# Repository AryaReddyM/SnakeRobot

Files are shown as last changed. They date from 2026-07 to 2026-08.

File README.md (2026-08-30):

# Teleoperated Snake Robot

A six-segment serpentine robot built with the intention to aid in search and rescue efforts where people or other robots cannot help. It is fully untethered, controlled over Bluetooth from an Xbox controller, and has a forward-facing camera.

I chose this form factor because I thought snake robots would be better suited for confined-space inspection where wheeled or legged robots can't fit. This is a testbed for that mechanism, not a deployable system.

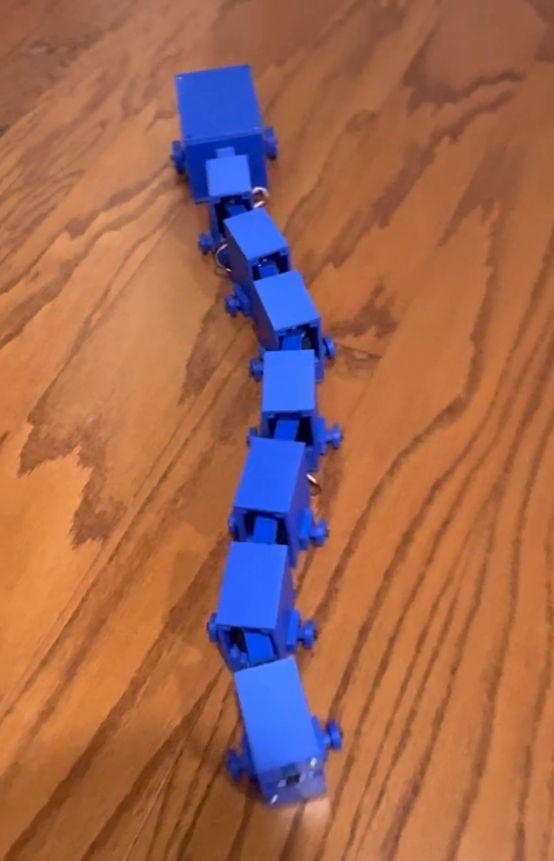
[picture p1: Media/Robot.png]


[Robot Demo](https://youtube.com/shorts/Uw1LnG1LLQQ?feature=share)

## What it does

- Travels forward on flat hard surfaces with a sinusoidal traveling-wave gait
- Steers through a graded joint offset that arcs the body, though turning is weak
- Streams video from an ESP32-CAM

## Hardware

- **Servos** - 6× Feetech STS3215 serial bus servos
- **Main controller** - ESP32-WROVER
- **Servo interface** - Waveshare serial bus servo driver board
- **Camera** - ESP32-CAM
- **Power** - 2S 7.4V LiPo, 1500mAh, with LM2596 buck converters to step down voltage for ESP32s
- **Control** - Xbox controller over Bluetooth via Bluepad32
- **Structure** - 3D-printed PLA shells

## How it works

Six servos are chained on a single TTL bus. Each servo sets the angle between two adjacent shells. Forward motion comes from propagating a sine wave down the body:

```
target[i] = center + amplitude × sin(2π·f·t + i·φ)
```

with a phase offset of `φ = 2π/N`, producing one full wave along the body.

| | | |
|---|---|---|
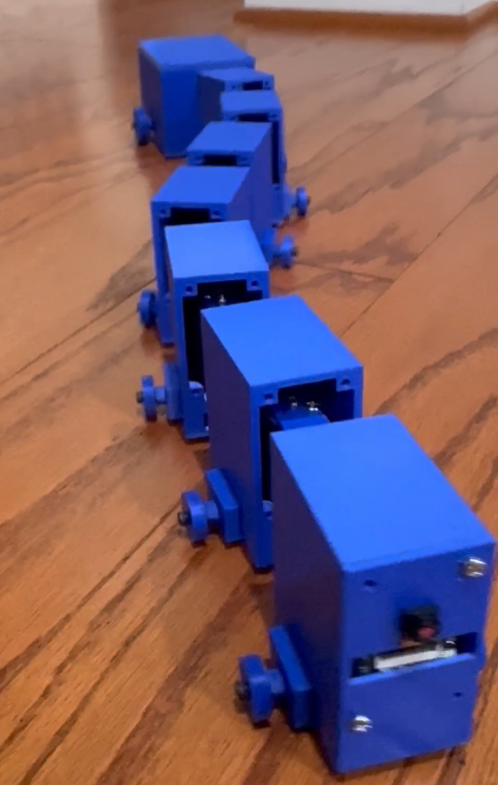
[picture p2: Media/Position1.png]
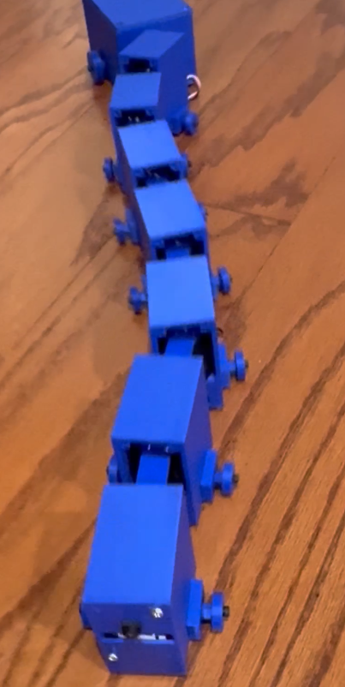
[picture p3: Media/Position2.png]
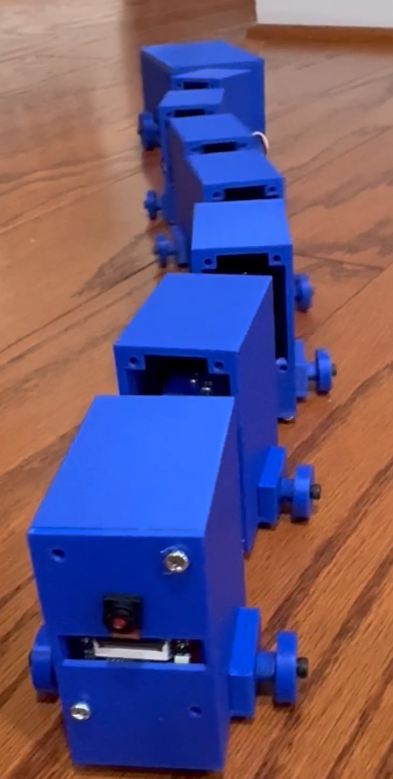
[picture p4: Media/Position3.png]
|  |  |  |

Steering applies a per-joint offset that biases the wave's center, bending the body into an arc that the wave then travels along.

## Problems

### Serpentine Gait
I learned a serpentine gait requires more friction when moving horizontally than forward/back through a series of attempts and design changes.

**1. Printed rails:** Longitudinal PLA rails on each segment's bottom. This didn't really change the friction in any way, so it was pretty much the same as just sliding on the raw shell bottom.

**2. Rubber pads:** I glued rubber strips along the rails, since I thought more grip would mean more thrust. I didn't realize that this also meant more friction forwards, as well as horizontally. The high amount of friction in both directions caused the segment to buckle and go upwards.

**3: Passive wheels.** I replaced the shell's bottom with passive wheels that rotate when going forward, but drag when going horizontally. This decreased the forward friction, generating more thrust in the serpentine gait.

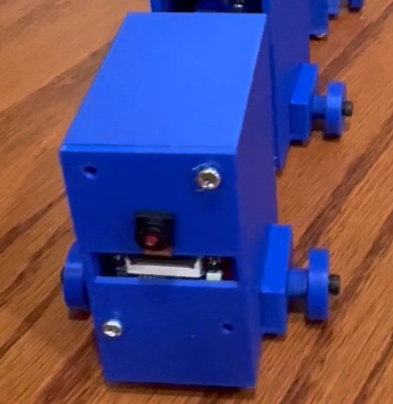
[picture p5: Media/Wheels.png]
Wheel carrier


### Turning

Turning is weak and the robot cannot pivot in place. I spent a long time on this, but with my current design, it wasn't possible to improve turning without sacrificing forward thrust.

**A statically bent body produces no yaw.** My first instinct was to hold one joint at an angle as a rudder. A frozen joint does no work against the ground, so it produces no torque. Only moving joints generate forces, and symmetric motion cancels to zero yaw over a cycle.

**The wheels work against turning.** They resist lateral sliding, which is what makes forward motion work. But turning requires the body to rotate, and rotation means sliding sideways — so the thing that fixed my forward speed cost me turning authority.

**The uniform offset works, but barely.** Bending the whole body into an arc and letting the wave travel along it produces some rotation, but not much. With ±17.58 degrees of joint range, total body curvature maxes out around 105 degrees, with high offsets stalling the robot, and low ones not turning much.

### Destroyed Parts

An early ESP32-WROVER died to current transients from servo stalls conducted through a shared ground wire. Also, a short circuit occurred due to a badly soldered wire for the input voltage pin of the buck converter inside of the electronics box. This short circuit caused a small explosion in the box, and cooked the second ESP32-WROVER, a Waveshare Serial Bus Servo Driver Board, and my buck converter.

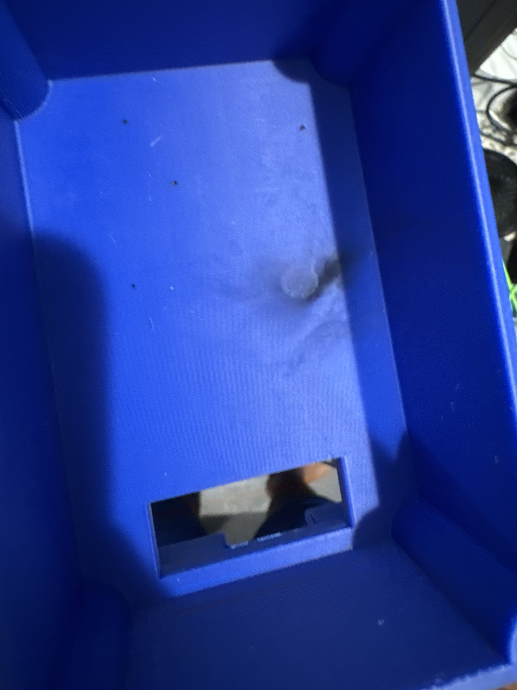
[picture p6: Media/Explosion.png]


### Heavy Electronics Box
The battery, driver board, buck converter, and ESP32 are too large to fit inside the standard segment design, so they are in a towed box connected by a passive joint. At first, I used the same rail design I had used for my regular segments, but this didn't allow the box to move well, weighing the entire robot down and making it unable to move. Then, I used forward facing wheels I used on the regular segments. This allows the box to move much easier than before, allowing the rest of the robot to move as well.

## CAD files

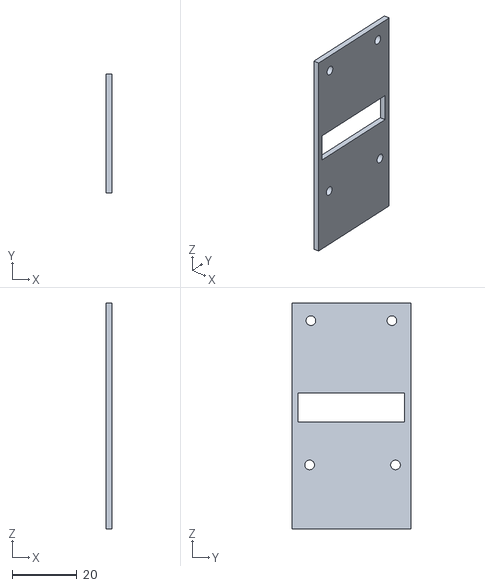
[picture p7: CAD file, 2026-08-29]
CAD/Head/Snake Head Shell Front.stl
2.00 x 37.0 x 70.0

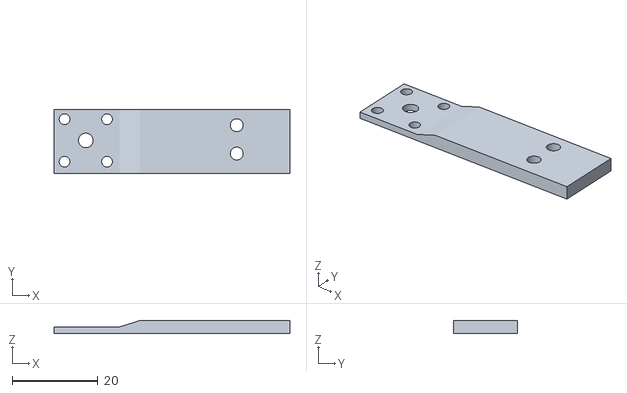
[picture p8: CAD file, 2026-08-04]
CAD/Segment/Flat Link.stl
55.0 x 15.0 x 3.00

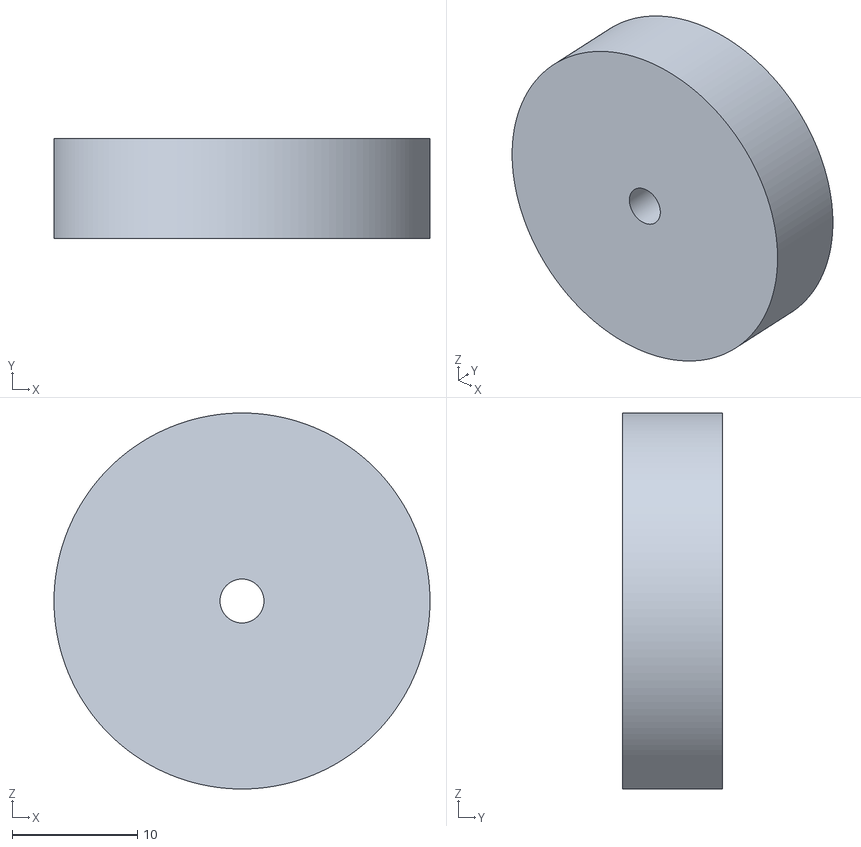
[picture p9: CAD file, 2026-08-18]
CAD/Tail/Snake Tail Wheel.stl
30.0 x 8.00 x 30.0

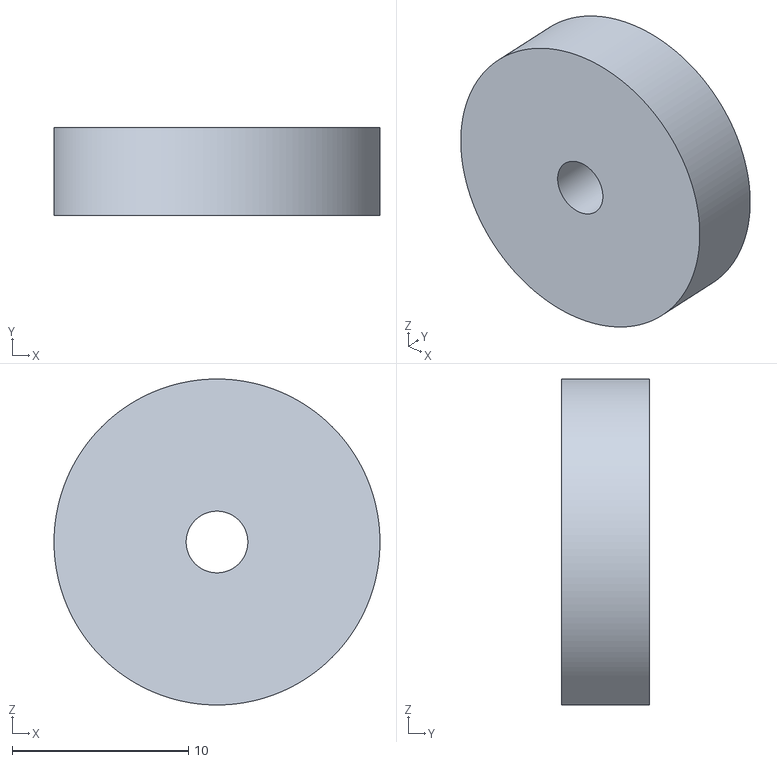
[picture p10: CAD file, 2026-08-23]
CAD/Head/Snake Head Wheel.stl
18.5 x 5.00 x 18.5

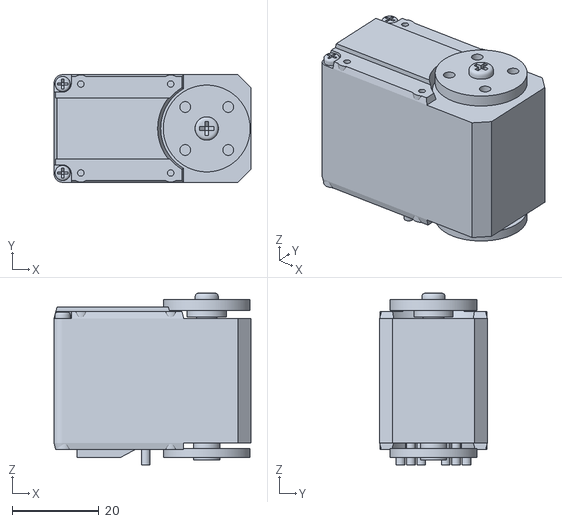
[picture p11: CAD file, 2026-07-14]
CAD/Segment/STS3215 Servo.stl
45.4 x 24.8 x 39.6

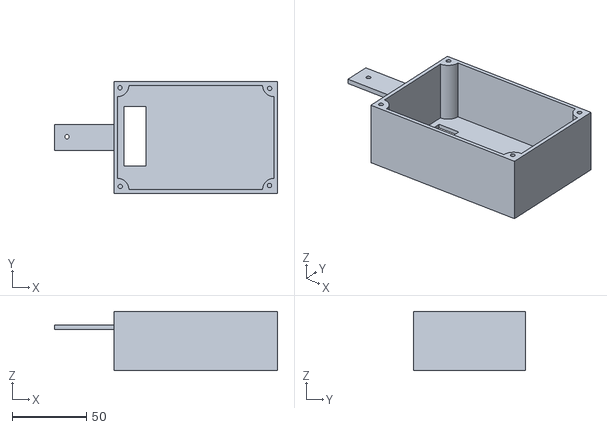
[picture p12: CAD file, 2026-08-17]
CAD/Tail/Snake Tail Top.stl
150.0 x 75.0 x 40.0

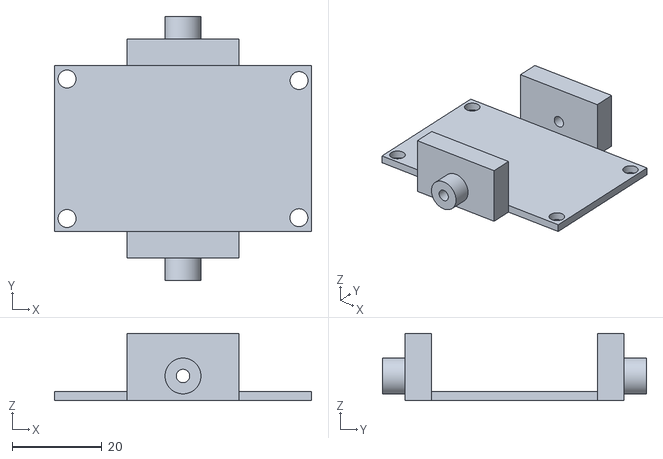
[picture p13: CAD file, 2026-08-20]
CAD/Head/Snake Head Shell Bottom.stl
57.4 x 59.0 x 15.0

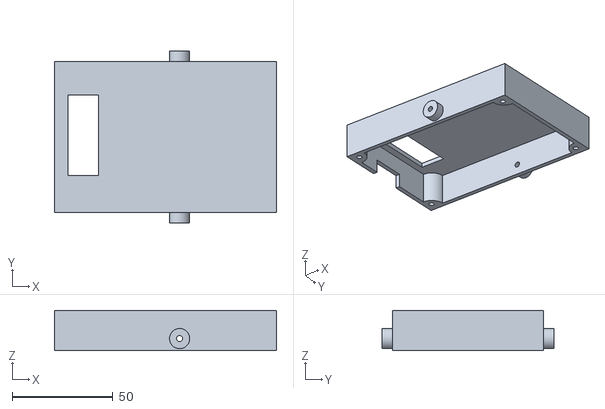
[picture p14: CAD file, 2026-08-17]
CAD/Tail/Snake Tail Bottom.stl
110.0 x 85.0 x 20.0

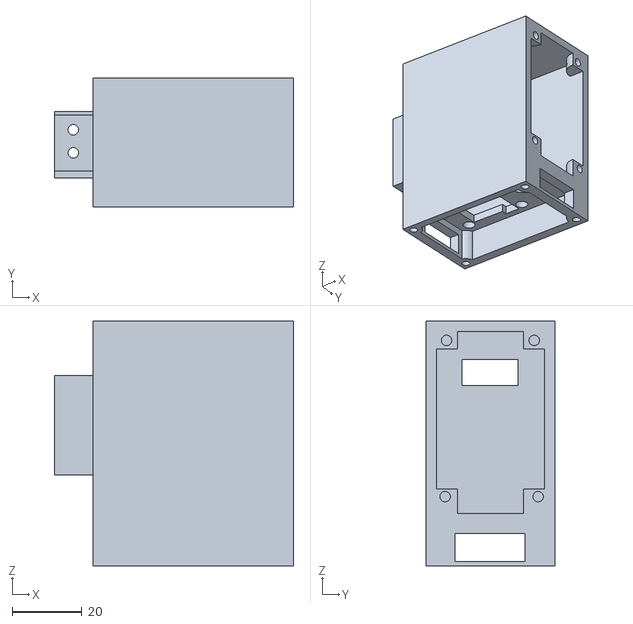
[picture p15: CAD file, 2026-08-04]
CAD/Head/Snake Head Shell.stl
68.4 x 37.0 x 70.1

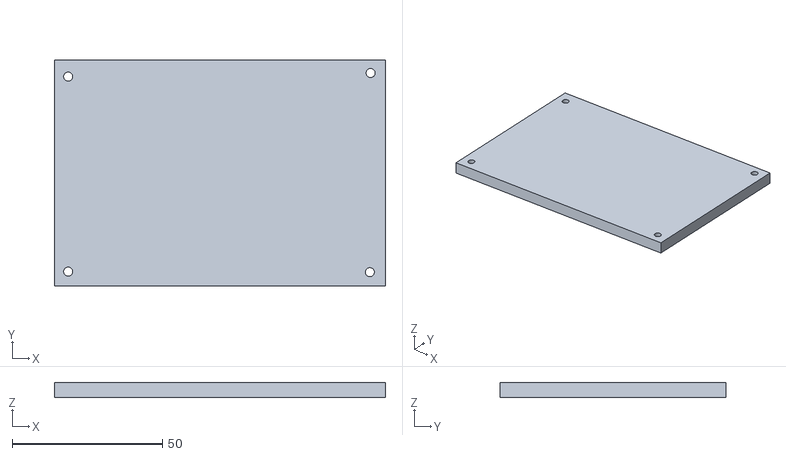
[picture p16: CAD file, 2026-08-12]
CAD/Tail/Snake Tail Bottom Floor.stl
110.0 x 75.0 x 5.00

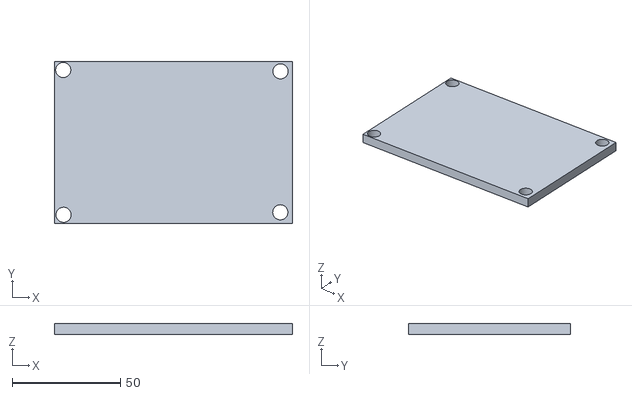
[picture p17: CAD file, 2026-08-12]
CAD/Tail/Snake Tail Top Roof.stl
110.0 x 75.0 x 5.00

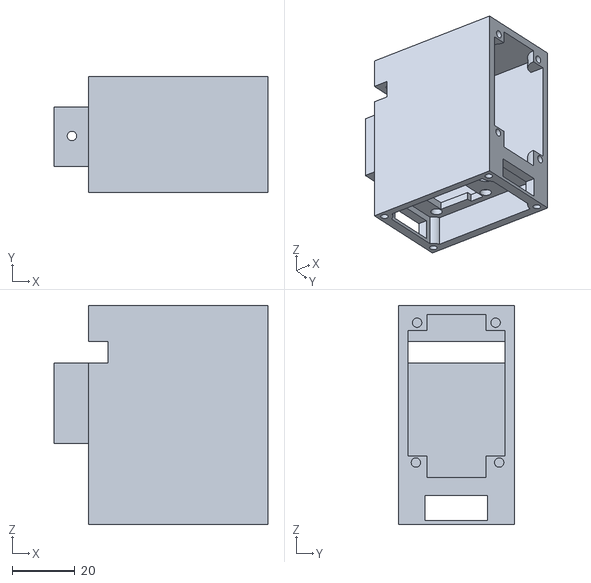
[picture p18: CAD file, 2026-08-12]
CAD/Tail/Snake Tail Shell.stl
68.4 x 37.0 x 70.1

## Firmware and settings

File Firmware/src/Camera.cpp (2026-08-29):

#include <Arduino.h>
#include "esp_camera.h"
#include <WiFi.h>
#include "esp_http_server.h"

const char* ssid = "Fios-2c3PM";
const char* password = "ink565jag85coop";

#define PWDN_PIN 32
#define RST_PIN -1
#define XCLK_PIN 0
#define SIOD_PIN 26
#define SIOC_PIN 27
#define Y9_PIN 35
#define Y8_PIN 34
#define Y7_PIN 39
#define Y6_PIN 36
#define Y5_PIN 21
#define Y4_PIN 19
#define Y3_PIN 18
#define Y2_PIN 5
#define VSYNC_PIN 25
#define HREF_PIN 23
#define PCLK_PIN 22

httpd_handle_t server = NULL;

#define BOUNDARY_STR "123456789000000000000987654321"
static const char* streamType = "multipart/x-mixed-replace;boundary=" BOUNDARY_STR;
static const char* boundary = "\r\n--" BOUNDARY_STR "\r\n";
static const char* headerFmt = "Content-Type: image/jpeg\r\nContent-Length: %u\r\n\r\n";

static esp_err_t streamHandler(httpd_req_t* req) {
  camera_fb_t* frame = NULL;
  esp_err_t err = ESP_OK;
  size_t dataLen = 0;
  uint8_t* data = NULL;
  char header[64];

  err = httpd_resp_set_type(req, streamType);
  if (err != ESP_OK) {
    return err;
  }

  while (true) {
    frame = esp_camera_fb_get();
    if (!frame) {
      Serial.println("Cam fail");
      err = ESP_FAIL;
    } else {
      dataLen = frame->len;
      data = frame->buf;
    }

    if (err == ESP_OK) {
      err = httpd_resp_send_chunk(
        req, boundary, strlen(boundary)
      );
    }

    if (err == ESP_OK) {
      size_t headerLen = snprintf(
        header, sizeof(header), headerFmt, dataLen
      );
      err = httpd_resp_send_chunk(
        req, header, headerLen
      );
    }

    if (err == ESP_OK) {
      err = httpd_resp_send_chunk(
        req, (const char*)data, dataLen
      );
    }

    if (frame) {
      esp_camera_fb_return(frame);
      frame = NULL;
      data = NULL;
    } else if (data) {
      free(data);
      data = NULL;
    }

    if (err != ESP_OK) {
      break;
    }
  }

  return err;
}

void startServer() {
  httpd_config_t config = HTTPD_DEFAULT_CONFIG();
  config.server_port = 81;

  httpd_uri_t uri = {
    .uri = "/stream",
    .method = HTTP_GET,
    .handler = streamHandler,
    .user_ctx = NULL
  };

  if (httpd_start(&server, &config) == ESP_OK) {
    httpd_register_uri_handler(server, &uri);
  }
}

void setup() {
  Serial.begin(115200);
  Serial.setDebugOutput(true);
  Serial.println();

  camera_config_t camConfig;
  camConfig.ledc_channel = LEDC_CHANNEL_0;
  camConfig.ledc_timer = LEDC_TIMER_0;
  camConfig.pin_d0 = Y2_PIN;
  camConfig.pin_d1 = Y3_PIN;
  camConfig.pin_d2 = Y4_PIN;
  camConfig.pin_d3 = Y5_PIN;
  camConfig.pin_d4 = Y6_PIN;
  camConfig.pin_d5 = Y7_PIN;
  camConfig.pin_d6 = Y8_PIN;
  camConfig.pin_d7 = Y9_PIN;
  camConfig.pin_xclk = XCLK_PIN;
  camConfig.pin_pclk = PCLK_PIN;
  camConfig.pin_vsync = VSYNC_PIN;
  camConfig.pin_href = HREF_PIN;
  camConfig.pin_sccb_sda = SIOD_PIN;
  camConfig.pin_sccb_scl = SIOC_PIN;
  camConfig.pin_pwdn = PWDN_PIN;
  camConfig.pin_reset = RST_PIN;
  camConfig.xclk_freq_hz = 20000000;
  camConfig.pixel_format = PIXFORMAT_JPEG;
  camConfig.frame_size = FRAMESIZE_VGA;
  camConfig.jpeg_quality = 12;
  camConfig.fb_count = 2;

  esp_err_t initErr = esp_camera_init(&camConfig);
  if (initErr != ESP_OK) {
    Serial.printf("Init error 0x%x", initErr);
    return;
  }

  sensor_t * s = esp_camera_sensor_get();
  if (s != NULL) {
    s->set_vflip(s, 1);
    s->set_hmirror(s, 1);
  }

  WiFi.begin(ssid, password);
  while (WiFi.status() != WL_CONNECTED) {
    delay(500);
    Serial.print(".");
  }
  Serial.println("");
  Serial.println("Connected");

  startServer();

  Serial.print("Stream: http://");
  Serial.print(WiFi.localIP());
  Serial.println(":81/stream");
}

void loop() {
  delay(10000);
}

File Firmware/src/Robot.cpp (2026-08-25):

#include <Arduino.h>
#include <SCServo.h>
#include <Bluepad32.h>

#define frequency 0.8
#define segments 6
#define phaseOffset (2 * PI / segments)

#define servoMax 1650
#define servoMin 1250
#define range ((servoMax - servoMin) / 2)

SMS_STS servos;
GamepadPtr gamepad;

float mapFloat(float x, float inMin, float inMax, float outMin, float outMax) {
    return (x - inMin) / (inMax - inMin) * (outMax - outMin) + outMin;
}

void OnConnectedGamepad(GamepadPtr gp) {
    Serial.println("Gamepad connected");
    gamepad = gp;
}

void OnDisconnectedGamepad(GamepadPtr gp) {
    Serial.println("Gamepad disconnected");
    gamepad = nullptr;
}

void calibrateCenters() {
    for (int i = 0; i < segments; i++) {
        servos.WritePosEx(i, (servoMax + servoMin) / 2, 0, 0);
        delay(500);
    }
}

void setup() {
    Serial.begin(115200);
    Serial2.begin(1000000, SERIAL_8N1, 22, 21);
    delay(500);
    servos.pSerial = &Serial2;

    calibrateCenters();

    BP32.setup(&OnConnectedGamepad, &OnDisconnectedGamepad);
}

unsigned long lastUpdate = 0;
unsigned long lastRead = 0;
void loop() {
    BP32.update();

    if (gamepad && gamepad->isConnected()) {
        if (gamepad->a()) {
            calibrateCenters();
        }

        if (millis() - lastUpdate >= 20) {
            lastUpdate = millis();

            int leftY = -(gamepad->axisY());
            int leftX = gamepad->axisX();

            float offset = 0;
            if (abs(leftX) > 250) {
                offset = mapFloat(leftX, -512, 512, -120, 120);
            }

            if (leftY > 150 || leftX > 350 || leftX < -350) {
                float t = millis() / 1000.0;

                for (int i = 0; i < segments; i++) {
                    float wave = sin(2 * PI * frequency * t + i * phaseOffset);

                    float jointOffset = offset * (float)(segments - i) / segments;
                    float amp = range - fabs(jointOffset);
                    int target = (int)((servoMin + servoMax) / 2 + jointOffset + wave * amp);

                    servos.WritePosEx(i, target, 2000, 200);
                }
            }
        }

        if (millis() - lastRead >= 503) {
            lastRead = millis();

            if (millis() - lastUpdate > 5) {
                int pos = servos.ReadPos(0);
                if (pos >= 0) Serial.println(pos);
            }
        }
    }
}

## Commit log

2026-07-08 Testing Servos
2026-07-12 Test Snake Chain w/ Two Servos
2026-07-14 First Iteration Snake Robot CAD
    [SnakeSegment.stl]
2026-07-14 Second Iteration Snake Robot CAD
    [SnakeSegment.stl]
2026-07-14 Split Second Iteration CAD Into Parts
    [Flat Link.stl, STS3215 Servo.stl, Snake Shell Front.stl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]
2026-07-17 Third Iteration Snake Robot CAD
    [Flat Link.stl, Snake Shell Bottom.stl, Snake Shell Front.stl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]
2026-07-21 Add Asynchronous Timer Instead of Delay
2026-07-23 Fourth Iteration Snake Robot CAD
    [Flat Link.stl, Snake Shell.stl]
2026-07-27 Fifth Iteration Snake Robot CAD
    [Snake Shell Bottom.stl, Snake Shell.stl]
2026-07-30 Creating ESP32 Camera Class and Split PlatformIO Environments
2026-07-31 Sixth Iteration Snake Robot CAD
    [Snake Shell.stl]
2026-08-02 Seventh Iteration Snake Robot CAD
    [Snake Shell Bottom.stl, Snake Shell.stl]
2026-08-04 Eighth Iteration Snake Robot CAD
    [Flat Link.stl, Snake Shell Bottom.stl, Snake Shell Front.stl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]
2026-08-07 Calibrate Servo Positions on Start and Button Press
2026-08-08 Recenter Servo and Constrain Movements
2026-08-10 Fixing Servo Stalling (Stalling Broke ESP32)
    [Robot.cpp]
2026-08-12 Robot Snake Tail CAD
    [Snake Tail Bottom Floor.stl, Snake Tail Bottom.stl, Snake Tail Shell.stl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]
2026-08-12 Second Iteration Robot Snake Tail CAD
    [Snake Tail Bottom Floor.stl, Snake Tail Bottom.stl, Snake Tail Top Roof.stl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]
2026-08-12 Web Camera Server For ESP32-Cam
2026-08-13 Third Iteration Robot Snake Tail CAD
    [Snake Tail Bottom.stl]
2026-08-14 Fourth Iteration Robot Snake Tail CAD
    [Snake Tail Top.stl]
2026-08-16 Fifth Iteration Robot Snake Tail CAD
    [Snake Tail Bottom.stl]
2026-08-16 Sixth Iteration Robot Snake Tail CAD
    [Snake Tail Bottom.stl, Snake Tail Top.stl]
2026-08-17 Fixed Calibration
2026-08-17 Seventh Iteration Robot Snake Tail CAD
    [Snake Tail Bottom.stl, Snake Tail Top.stl, Snake Tail Wheel.stl]
2026-08-18 Eigth Iteration Robot Snake Tail CAD
    Wheel is too tight with the screw. To fix this, I widened the wheel's bore to 3.5mm so it has more margin from the M3 screw and can rotate freely.
    [Snake Tail Wheel.stl]
2026-08-20 Ninth Iteration Snake Robot CAD
    The rails on the shell bottom didn't increase friction while moving left/right while maintaining it forward/back, even with rubber strips, so I added one directional wheels to solve that issue.
    [Snake Shell Bottom.stl, Snake Wheel.stl]
2026-08-21 Tenth Iteration Snake Robot CAD
    The wheels were on the same level as the screw heads, which I didn't account for, which blocked the wheels from spinning. I increased the wheel's diameter by 2mm, making it 17mm.
    [Snake Wheel.stl]
2026-08-23 Fixed Bias Towards Leftside
    [Snake Wheel.stl]
2026-08-25 First Iteration Snake Head CAD
    [Snake Head Shell Bottom.stl, Snake Head Shell Front.stl, Snake Head Shell.stl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]
2026-08-29 Second Iteration Robot Snake Head CAD
    [Snake Head Shell Front.stl]
2026-08-29 Flipped The Video Playback Upside-down because I Mounted the ESP32 Camera Module Upside-down
    [Snake Head Shell Front.stl]
2026-08-30 Fixed README
    Clarified explanation of servo operation and motion propagation.
